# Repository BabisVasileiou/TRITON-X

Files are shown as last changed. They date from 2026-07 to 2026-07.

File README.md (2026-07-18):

<div align="center">

# 🤖 TRITON-X
### Multi-Mode Autonomous Unmanned Ground Vehicle (UGV)

**Μελέτη και Ανάπτυξη Μη Επανδρωμένου Συστήματος — Εργασία 2**
MSc Πρόγραμμα ΠΑΔΑ (PADA) · Πανεπιστήμιο Δυτικής Αττικής




[]()

*Ένα ρομποτικό όχημα εδάφους έξι λειτουργικών καταστάσεων, με τηλεχειρισμό μέσω Wi-Fi, ζωντανή μετάδοση βίντεο, αυτόνομη αποφυγή εμποδίων και χαρτογράφηση κάλυψης — βασισμένο στο μηχατρονικό μοντέλο Controller–Plant.*

[Αρχιτεκτονική](#-αρχιτεκτονική-συστήματος) ·
[Λειτουργίες](#-6-λειτουργικές-καταστάσεις-fsm) ·
[Firmware](#-λογισμικό--firmware) ·
[Τεκμηρίωση](#-τεκμηρίωση--docs) ·
[Εγκατάσταση](#-εγκατάσταση--γρήγορη-εκκίνηση)

</div>

---

## 📖 Περιγραφή Έργου

Το **TRITON-X** είναι η εξέλιξη ενός απλούστερου ρομπότ αποφυγής εμποδίων 4 αισθητήρων (Εργασία 1) σε ένα πλήρες, πολυλειτουργικό αυτόνομο όχημα εδάφους (UGV). Ο πυρήνας ελέγχου βασίζεται σε **Arduino UNO R3**, ενισχυμένος με έναν **ESP32-CAM** ως ασύρματο συνεπεξεργαστή (co-processor) για video streaming και web-based τηλεχειρισμό.

Το σύστημα ακολουθεί το **βασικό μηχατρονικό μοντέλο** (Controller–Plant–Feedback) της προδιαγραφής εργασίας: αισθητήρια (S) → μικροελεγκτής (μC) → ενεργοποιητές (A), με πλήρη ανάδραση (sensor fusion, Kalman filtering, closed-loop control).

Το ρομπότ διαθέτει **6 ανεξάρτητες λειτουργικές καταστάσεις** (Finite State Machine) — από απλό χειροκίνητο τηλεχειρισμό μέσω κινητού, μέχρι πλήρως αυτόνομη χαρτογράφηση χώρου με occupancy grid.

### Γιατί TRITON-X;

| Χαρακτηριστικό | Περιγραφή |
|---|---|
| 🎮 **Dual-mode τηλεχειρισμός** | Virtual joystick *και* έλεγχος με κλίση κινητού (gyroscope) μέσω browser |
| 📷 **Live FPV streaming** | ESP32-CAM MJPEG stream ενσωματωμένο στο web dashboard |
| 🧭 **Sensor fusion** | Kalman filtering στο υπερηχητικό, IMU 6-άξονων, 8× IR αισθητήρες, οδομετρία encoder |
| 🗺️ **Αυτόνομη χαρτογράφηση** | Boustrophedon coverage algorithm + occupancy grid 20×20, live μετάδοση στον browser |
| ⚙️ **OOP αρχιτεκτονική** | Καθαρές C++ κλάσεις (`KalmanFilter`, `Sonar`, `MotorDriver`, `OccupancyGrid`) |
| ⏱️ **Non-blocking σχεδίαση** | Αρχιτεκτονική `millis()` σε όλο το firmware — καμία μπλοκαριστική `delay()` |

---

## 🏗️ Αρχιτεκτονική Συστήματος

```
┌─────────────────────────────────────────────────────────────┐
│                      ARDUINO UNO R3                          │
│                 (Κύριος Ελεγκτής — μC)                       │
│                                                                │
│  ┌─────────── SENSORS (S) ───────────┐  ┌── ACTUATORS (A) ─┐ │
│  │ • HC-SR04 Ultrasonic (on SG90)     │  │ • L298N →        │ │
│  │ • 8× IR (4 obstacle + 4 cliff)     │  │   2× DC Motors    │ │
│  │ • MPU-6050 IMU (I2C)               │  │ • SG90 Servo      │ │
│  │ • 2× Photoelectric Encoders        │  │ • LCD 1602 (HMI)  │ │
│  │ • PCF8574T I2C Expander            │  └───────────────────┘ │
│  └─────────────────────────────────────┘                      │
│                                                                │
│         Λογική Ελέγχου: 6-mode FSM · non-blocking             │
│         millis() · Kalman Filter · OOP (C++ classes)          │
└───────────────────────────┬────────────────────────────────────┘
                             │ UART (SoftwareSerial, polling encoders)
                             │ MODE: / JOY: / GYR: / TEL: / MAP:
┌───────────────────────────┴────────────────────────────────────┐
│                    ESP32-CAM (AI-Thinker)                       │
│               (Ασύρματος Συνεπεξεργαστής)                       │
│                                                                  │
│  • Wi-Fi Access Point  ("TRITON-X")                              │
│  • HTTP Server (port 80)  — Web Dashboard                        │
│  • WebSocket Server (port 81) — Joystick / Gyro / Telemetry / Map │
│  • MJPEG Camera Stream (port 82) — OV2640                        │
└───────────────────────────┬──────────────────────────────────────┘
                             │ Wi-Fi 802.11
┌───────────────────────────┴──────────────────────────────────────┐
│                     📱 Browser (Mobile / Desktop)                  │
│  • Live FPV video feed        • Virtual joystick (touch)           │
│  • Gyroscope tilt control     • Live occupancy grid canvas         │
│  • Telemetry bar (distance, battery, state)  • Mode selector       │
└─────────────────────────────────────────────────────────────────┘
```

Πλήρες πρωτόκολλο επικοινωνίας UART μεταξύ των δύο μονάδων: [`docs/UART_PROTOCOL.txt`](docs/UART_PROTOCOL.txt)

---

## ⚡ Ισχύς — Power Architecture

Δύο **ανεξάρτητες** ρελές 5V, με κοινή γείωση, ώστε το ESP32-CAM (με τις απότομες αιχμές ρεύματος του Wi-Fi) να μην προκαλεί brown-out στο Arduino:

```
6× AA (9V) battery pack
        │
        ├──► Rocker Switch ──► L298N 12V_IN
        │                          │
        │                    Onboard 5V regulator
        │                          │
        │                          ▼
        │                  +5V_MCU rail ──► Arduino, sensors, servo
        │
        └──► DC-DC Step-Down (6.5–40V → 5V, 1.5A)
                                   │
                                   ▼
                          +5V_CAM rail ──► ESP32-CAM (exclusively)
```

> ⚠️ **Κρίσιμη σημείωση:** Η τροφοδοσία είναι πάντα **6×AA (9V)**, ποτέ Li-Po. Ο εσωτερικός ρυθμιστής του L298N **δεν επαρκεί** για τις αιχμές ρεύματος του ESP32-CAM στο Wi-Fi — απαιτείται ξεχωριστός DC-DC step-down μετατροπέας.

---

## 🎛️ 6 Λειτουργικές Καταστάσεις (FSM)

| # | Mode | Περιγραφή | Βασικά στοιχεία |
|---|---|---|---|
| 0 | **IDLE** | Κατάσταση αναμονής | Κινητήρες σταματημένοι, LCD εμφανίζει επιλογή mode |
| 1 | **MANUAL** | Τηλεχειρισμός με virtual joystick από browser | Touch UI → ESP32-CAM → UART → PWM differential drive |
| 2 | **LEVEL** | Τηλεχειρισμός με κλίση κινητού (tilt-to-drive) | DeviceOrientation API, dead-zone & smoothing filter |
| 3 | **LINE** | Ακολούθηση γραμμής | 2× IR κάτω, PD controller, ταυτόχρονη αποφυγή εμποδίων με HC-SR04 |
| 4 | **OBSTACLE** | Αυτόνομη αποφυγή εμποδίων | FSM `CRUISING → SCAN → ESCAPE → CLIFF_ESCAPE`, Kalman filter, hardware interrupts |
| 5 | **MAP** | Αυτόνομη χαρτογράφηση κάλυψης | Boustrophedon algorithm, dead-reckoning odometry, occupancy grid 20×20 |

---

## 🔧 Εξοπλισμός — Hardware

### Από Εργασία 1 (υπάρχοντα)

Arduino UNO R3 + Sensor Shield v5.0 · L298N Dual H-Bridge · 2× DC Gear Motor + caster wheel · Ακρυλικό σασί 2WD · HC-SR04 + SG90 Servo · 4× IR sensors (μπροστά) · LCD 1602 I2C

### Νέα προμήθεια για Εργασία 2

ESP32-CAM (AI-Thinker, OV2640) · DC-DC Step-Down 6.5–40V→5V 1.5A · 2× Photoelectric Encoder (18 PPR εμπειρικά) · MPU-6050 GY-521 IMU · 4× IR sensors (πίσω) · PCF8574T I2C Expander

Πλήρης χάρτης ακίδων (pin map): αντιστοιχεί στον **Πίνακα 2.4** της αναφοράς — δες το κύριο έγγραφο αναφοράς στο [`docs/`](docs/).

---

## 💻 Λογισμικό — Firmware

```
TRITON_X_UNO/              # Arduino UNO — κύριο firmware
└── TRITON_X.ino            # 6-mode FSM, OOP classes, non-blocking control loop

TRITON_X_ESP32/             # ESP32-CAM — ασύρματος συνεπεξεργαστής
└── ESP32_CAM.ino            # Wi-Fi AP, HTTP/WebSocket/MJPEG server, web dashboard
```

### Βασικές OOP κλάσεις (Arduino)

| Κλάση | Ευθύνη |
|---|---|
| `KalmanFilter` | Φιλτράρισμα θορύβου μετρήσεων HC-SR04· reset ανά γωνία σάρωσης |
| `Sonar` | Έλεγχος HC-SR04 + servo σάρωσης, non-blocking |
| `MotorDriver` | Αφαίρεση (abstraction) του L298N — differential drive, PWM |
| `OccupancyGrid` | Δομή 20×20 grid, ενημέρωση mode MAP, σειριοποίηση για μετάδοση |

### Πρωτόκολλο επικοινωνίας UART (Arduino ⇄ ESP32-CAM)

| Πρόθεμα | Κατεύθυνση | Περιεχόμενο |
|---|---|---|
| `MODE:` | ESP32 → Arduino | Αλλαγή λειτουργικής κατάστασης |
| `JOY:` | ESP32 → Arduino | Συντεταγμένες joystick (x, y) |
| `GYR:` | ESP32 → Arduino | Δεδομένα κλίσης κινητού |
| `TEL:` | Arduino → ESP32 | Τηλεμετρία (απόσταση, mode, μπαταρία) |
| `MAP:` | Arduino → ESP32 | Ενημέρωση occupancy grid κελιού |

Αναλυτικά: [`docs/UART_PROTOCOL.txt`](docs/UART_PROTOCOL.txt)

> 📌 **Γνωστός περιορισμός:** Η βιβλιοθήκη `SoftwareSerial` δεσμεύει όλα τα PCINT vectors, καθιστώντας αδύνατη τη χρήση interrupt-driven ανάγνωσης για τους encoders όταν είναι ενεργή η UART επικοινωνία με το ESP32-CAM. Οι encoders διαβάζονται επομένως με **polling**.

---

## 📚 Τεκμηρίωση — `docs/`

| Αρχείο | Περιεχόμενο |
|---|---|
| [`README_FIRST.txt`](docs/README_FIRST.txt) | Οδηγός εκκίνησης — τι να διαβάσεις πρώτο |
| [`UART_PROTOCOL.txt`](docs/UART_PROTOCOL.txt) | Πλήρης προδιαγραφή πρωτοκόλλου επικοινωνίας Arduino ⇄ ESP32-CAM |
| [`VALIDATION_REPORT.txt`](docs/VALIDATION_REPORT.txt) | Αποτελέσματα δοκιμών ανά λειτουργική κατάσταση |
| [`CHANGELOG.txt`](docs/CHANGELOG.txt) | Ιστορικό εκδόσεων firmware |
| [`SHA256_MANIFEST.txt`](docs/SHA256_MANIFEST.txt) | Checksums αρχείων για επαλήθευση ακεραιότητας |

---

## 🚀 Εγκατάσταση & Γρήγορη Εκκίνηση

### Προαπαιτούμενα

- [Arduino IDE](https://www.arduino.cc/en/software) 2.x
- Board package: **ESP32 by Espressif Systems** (Boards Manager)
- Βιβλιοθήκες: `Servo`, `Wire`, `LiquidCrystal_I2C`, `SoftwareSerial`, `WebSocketsServer` (Links2004), `ArduinoJson`, `esp32-camera`

### Βήματα

1. **Clone το repository**
   ```bash
   git clone https://github.com/BabisVasileiou/TRITON-X.git
   cd TRITON-X
   ```

2. **Arduino UNO** — άνοιξε `TRITON_X_UNO/TRITON_X.ino`, επίλεξε board *Arduino Uno*, upload.

3. **ESP32-CAM** — άνοιξε `TRITON_X_ESP32/ESP32_CAM.ino`, board *AI Thinker ESP32-CAM*.
   ⚠️ Χρειάζεται εξωτερικό USB-TTL adapter (GPIO0 → GND κατά το flashing). Μετά το upload, αφαίρεσε τη γέφυρα και κάνε reset.

4. **Σύνδεση** — ενεργοποίησε το ρομπότ, σύνδεσε το κινητό στο Wi-Fi **`TRITON-X`**, άνοιξε browser στο `http://192.168.4.1`, επίλεξε mode.

---

## 👤 Συγγραφέας

**Βασιλείου Χαράλαμπος**
MSc DRONES — Πανεπιστήμιο Δυτικής Αττικής
Μάθημα: Μελέτη και Ανάπτυξη Μη Επανδρωμένου Συστήματος

## 📜 Άδεια Χρήσης

Το firmware διανέμεται υπό την άδεια [MIT](LICENSE).

---

<div align="center">

*Αναπτύχθηκε ως τμήμα του μαθήματος "Μελέτη και Ανάπτυξη Μη Επανδρωμένου Συστήματος" — ΠΑΔΑ, 2026*

</div>

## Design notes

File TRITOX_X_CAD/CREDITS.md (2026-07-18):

# Αναφορά Πηγών Τρισδιάστατων Μοντέλων (CAD Attribution)

Το assembly του TRITON-X ενσωματώνει έτοιμα 3D μοντέλα εξαρτημάτων (Arduino, αισθητήρες, driver, κλπ.) τα οποία **δεν σχεδιάστηκαν από τον συγγραφέα** αλλά ελήφθησαν από δημόσιες βιβλιοθήκες CAD. Σύμφωνα με ακαδημαϊκή δεοντολογία και τους όρους χρήσης των περισσότερων πλατφορμών (GrabCAD, Thingiverse κ.ά.), κάθε τέτοιο μοντέλο αναφέρεται ρητά παρακάτω, με τον αρχικό δημιουργό και την πηγή.

> Τα μοντέλα αυτά χρησιμοποιούνται **αποκλειστικά για ακαδημαϊκή/εκπαιδευτική οπτικοποίηση** της διάταξης εντός του assembly `triton_x_assembly.SLDASM`, και δεν αποτελούν πρωτότυπη εργασία του συγγραφέα. Η γεωμετρία του σασί, των στηριγμάτων αισθητήρων (mounts) και κάθε custom εξαρτήματος σχεδιάστηκε από τον συγγραφέα και εξαιρείται από τον παρακάτω πίνακα.

## Πίνακας Πηγών

| # | Εξάρτημα (στο assembly) | Δημιουργός / Publisher | Πηγή (link) | Άδεια χρήσης |
|---|---|---|---|---|
| 1 | Σασί + κινητήρες + τροχοί (chassis+motors+wheels) | Mukarram Ibrahim | [grabcad.com/library/smart-car-kit-mechanical-design-for-educational-robotics-platform-1](https://grabcad.com/library/smart-car-kit-mechanical-design-for-educational-robotics-platform-1) | GrabCAD Open Engineering |
| 2 | Arduino UNO R3 | Andrew Whitham | [grabcad.com/library/arduino-uno-r3-1](https://grabcad.com/library/arduino-uno-r3-1) | GrabCAD Open Engineering |
| 3 | Arduino Sensor Shield v5.0 | Tijani JOUINI | [grabcad.com/library/sensor-shield-v5-0-1](https://grabcad.com/library/sensor-shield-v5-0-1) | GrabCAD Open Engineering |
| 4 | ESP32-CAM | Dũng Phan | [grabcad.com/library/esp32-cam-wifi-bluetooth-1](https://grabcad.com/library/esp32-cam-wifi-bluetooth-1) | GrabCAD Open Engineering |
| 5 | PCF8574 I2C Expander | roberto valeri | [grabcad.com/library/pcf8574-multiplexer-1](https://grabcad.com/library/pcf8574-multiplexer-1) | GrabCAD Open Engineering |
| 6 | L298N Motor Driver | NITHISH CADEX | [grabcad.com/library/motor-driver-l298n-2](https://grabcad.com/library/motor-driver-l298n-2) | GrabCAD Open Engineering |
| 7 | Photoelectric Encoder | Gauthier Heiss | [grabcad.com/library/feetech-speed-sensor-ft-en-001-1](https://grabcad.com/library/feetech-speed-sensor-ft-en-001-1) | GrabCAD Open Engineering |
| 8 | HC-SR04 Ultrasonic | Henrique Fernandes | [grabcad.com/library/sensor-ultrassonico-hc-sr04-1](https://grabcad.com/library/sensor-ultrassonico-hc-sr04-1) | GrabCAD Open Engineering |
| 9 | SG90 Micro Servo | Matheus Frasson | [grabcad.com/library/sg90-micro-servo-9g-tower-pro-1](https://grabcad.com/library/sg90-micro-servo-9g-tower-pro-1) | GrabCAD Open Engineering |
| 10 | IR Sensor (Obstacle) | MRMS - WORKSHOP | [grabcad.com/library/ir-sensor-7](https://grabcad.com/library/ir-sensor-7) | GrabCAD Open Engineering |
| 11 | IR Sensor (Cliff, HW-201) | Gaborcz | [grabcad.com/library/hw-201-2](https://grabcad.com/library/hw-201-2) | GrabCAD Open Engineering |
| 12 | MPU-6050 Accelerometer/Gyro Module | Nelson Stoldt | [grabcad.com/library/mpu6050-accelerometer-module-1](https://grabcad.com/library/mpu6050-accelerometer-module-1) | GrabCAD Open Engineering |
| 13 | LCD 1602 I2C (16x2 Character Display) | Anders Lohmann | [grabcad.com/library/16x2-character-lcd-display-1](https://grabcad.com/library/16x2-character-lcd-display-1) | GrabCAD Open Engineering |
| 14 | Battery Holder (6× AA) | Hallo | [grabcad.com/library/battery-holder-5xaa-1](https://grabcad.com/library/battery-holder-5xaa-1) | GrabCAD Open Engineering |
| 15 | Rocker Switch (KCD1, 2-Pin) | PENNEL Patrice | [grabcad.com/library/kcd1-on-off-rocker-switch-2-pins-1](https://grabcad.com/library/kcd1-on-off-rocker-switch-2-pins-1) | GrabCAD Open Engineering |
| 16 | DC-DC Step-Down Converter | MainDesign | [grabcad.com/library/usb-dc-dc-step-down-1](https://grabcad.com/library/usb-dc-dc-step-down-1) | GrabCAD Open Engineering |

> ⚠️ **Σημείωση για τη στήλη "Άδεια χρήσης":** Όλα τα παραπάνω μοντέλα προέρχονται από το GrabCAD, όπου η προεπιλεγμένη άδεια δημοσίευσης είναι η **"GrabCAD Open Engineering"**, η οποία επιτρέπει ελεύθερη χρήση/τροποποίηση με υποχρεωτική αναφορά του δημιουργού. Πριν την τελική παράδοση, **επιβεβαίωσε ξεχωριστά σε κάθε σελίδα του GrabCAD** ότι δεν αναγράφεται διαφορετική/αυστηρότερη άδεια (σπάνιο αλλά πιθανό), ειδικά για τα part #1 (πλήρες σασί kit) και #16 (DC-DC converter), όπου μερικοί δημιουργοί περιορίζουν σε "Non-Commercial only".

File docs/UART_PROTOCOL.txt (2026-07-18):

================================================================
TRITON-X COMMUNICATION PROTOCOL  --  v4.0 Final
Newline-delimited ASCII lines. UART 9600 8N1 (ESP32 <-> UNO).
WebSocket text frames (Browser <-> ESP32, port 81).
================================================================

1. ESP32 -> ARDUINO UNO
----------------------------------------------------------------
  HB                    Link heartbeat, sent every 250 ms. The
                        UNO stops any running mode if no HB is
                        received for 1500 ms.
  MODE:MANUAL           Select a mode. Selection always performs
  MODE:LEVEL            a full safe transition (motors stop, all
  MODE:LINE             FSMs reset, servo centered) and then
  MODE:OBSTACLE         waits for START.
  MODE:MAPPING          Selecting MAPPING also zeros pose,
                        encoders and the ESP32 grid.
  CMD:START             Arm and run the selected mode.
  CMD:STOP              Immediate stop; mode stays selected.
  CMD:CLEAR_LOCK        Request release of a latched CLIFF LOCK.
                        Granted only on confirmed safe floor.
  CMD:RESET_MAP         Stop, zero pose/encoders and clear map.
  JOY:x,y               MANUAL command, x/y in -100..+100.
                        Sent every 100 ms, including neutral
                        JOY:0,0 (watchdog keep-alive).
  TLT:forward,turn      LEVEL command, values in -100..+100.

2. ARDUINO UNO -> ESP32
----------------------------------------------------------------
  MODE:<name>           Confirms the completed mode transition.

  EVENT:<text>          Asynchronous events, e.g. STARTED,
                        STOPPED, CLIFF_DETECTED, CLIFF_LOCKED,
                        CLIFF_CLEARED, SAFETY_LOCK_CLEARED,
                        CLEAR_LOCK_REJECTED, MAP_RESET,
                        MANUAL_COMMAND_TIMEOUT,
                        LEVEL_COMMAND_TIMEOUT,
                        LINE_OBSTACLE_STOP, OBSTACLE_FRONT,
                        BROWSER_LINK_LOST, PCF_FAULT_STOP,
                        START_REJECTED_NO_MODE,
                        START_REJECTED_LOCKED,
                        START_REJECTED_PCF, START_REJECTED_MPU.

  SYS:<10 fields>       Periodic system telemetry (250 ms; 500 ms
                        in MAPPING). Comma-separated:
                        mode, running(0/1), safety, modeState,
                        cliffBits(hex), obstacleBits(hex),
                        pcfHealthy(0/1), mpuHealthy(0/1),
                        sonarCm(0.1), headingDeg(0.1).
                        Bit order (bit0..bit3) for both the
                        cliff and the obstacle byte:
                        FrontLeft=bit0, FrontRight=bit1,
                        RearLeft=bit2, RearRight=bit3.

  POSE:<9 fields>       MAPPING pose telemetry every 250 ms:
                        x, y, headingDeg, sonarCm, state,
                        encLeft, encRight, travelCm, elapsedSec.

  RAY:<5 fields>        One world-referenced sonar ray:
                        originX, originY, bearingDeg,
                        distanceCm, hit(0/1).

3. BROWSER <-> ESP32 (WebSocket, port 81)
----------------------------------------------------------------
  Browser -> ESP32:
    CTRL:HB             Controller heartbeat. Loss for 4000 ms
                        forces STOP and disables the camera.
    CAM:ON / CAM:OFF    Enable / disable the MJPEG stream.
    CMD:RESET_MAP       Clears ESP32 grid, forwards to the UNO.
    MODE:<name>, CMD:START, CMD:STOP, CMD:CLEAR_LOCK,
    JOY:x,y, TLT:f,t    Forwarded to the UNO unchanged.

  ESP32 -> Browser:
    CTRL:ACTIVE         This client is the single controller.
    CTRL:BUSY           Another controller is already active.
    CAM:ON/OFF/ERROR    Camera state notification.
    TEL:{json}          Consolidated telemetry every 500 ms:
                        uno, mode, running, safety, cliff,
                        obstacle, pcf, mpu, sonar, heading,
                        x, y, state, encL, encR, travel,
                        elapsed, event, cameraReady, cameraOn.
    MAP:<900 chars>     Occupancy grid, row-major 30x30, one
                        character per cell:
                        0 unknown, 1 free, 2 occupied,
                        3 robot path. Broadcast every 1000 ms
                        while MAPPING is selected.
    EVENT:<text>        Forwarded UNO events.

4. SAFETY CHAIN SUMMARY
----------------------------------------------------------------
  Browser heartbeat lost (4 s)  -> ESP32 sends CMD:STOP.
  Browser disconnects           -> ESP32 sends CMD:STOP.
  UNO heartbeat lost (1.5 s)    -> UNO stops the running mode.
  JOY/TLT command lost (0.5 s)  -> MANUAL/LEVEL watchdog stop
                                   and neutral re-arm.
  Cliff detected                -> global recovery FSM, possible
                                   latched CLIFF LOCK.
================================================================

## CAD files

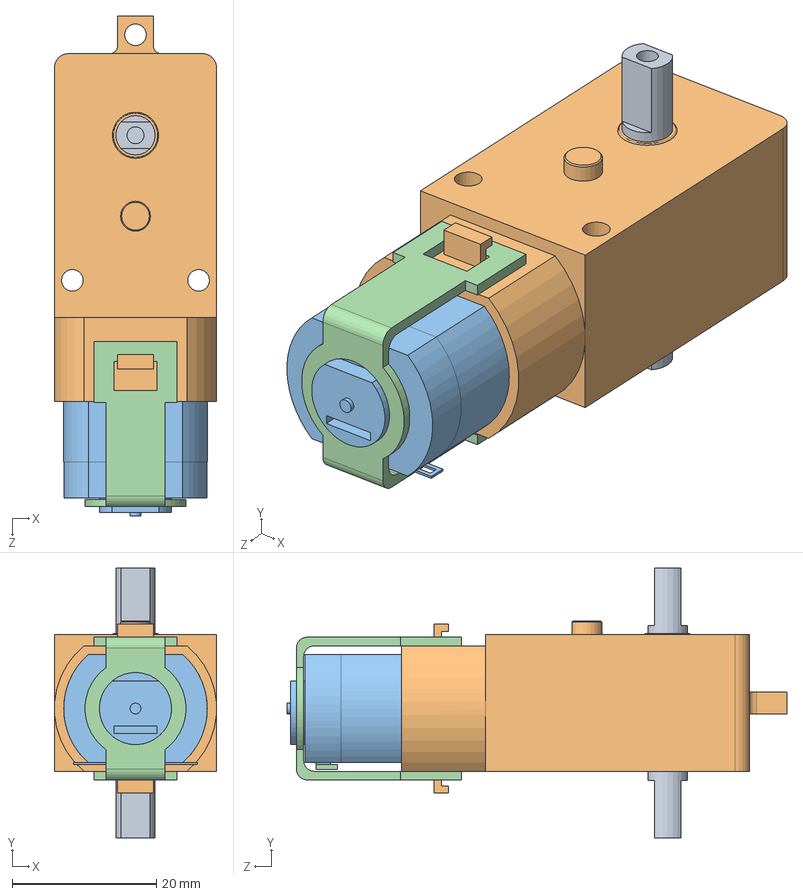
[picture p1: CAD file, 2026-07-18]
TRITOX_X_CAD/DC Motor.SLDASM
22.5 x 37.4 x 69.3 mm
Motor Shaft
Motor Casing
Driving Motor
Fasteners

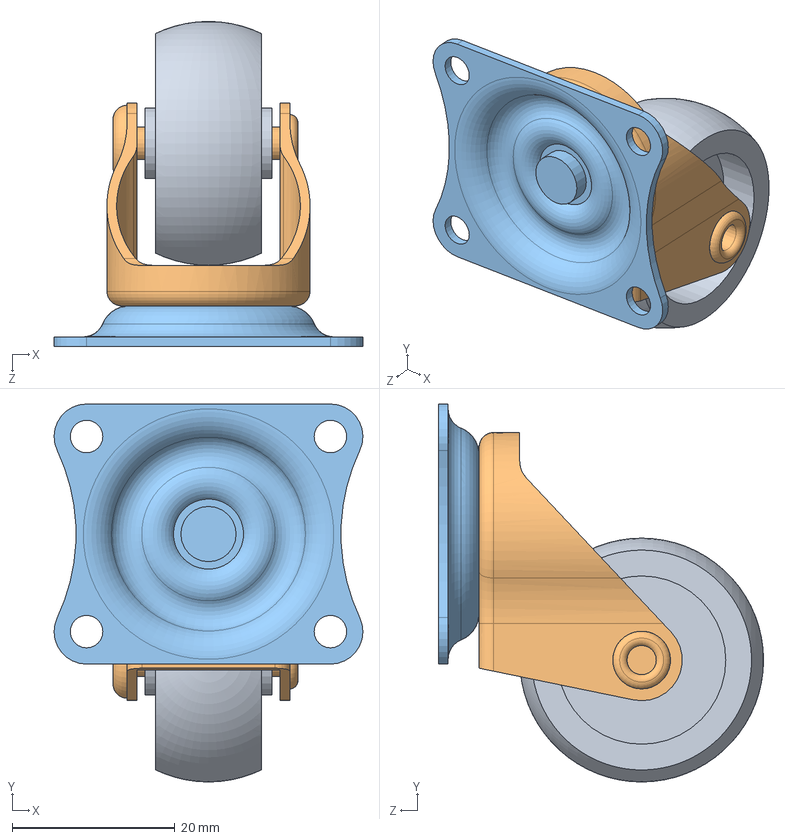
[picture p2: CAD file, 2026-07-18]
TRITOX_X_CAD/40mm rear wheel assy.SLDASM
38.0 x 46.5 x 40.0 mm
Caster_40mm_Wheel_30mm_01
Caster_40mm_Wheel_support_01
Caster_40mm_Swivel_plate_01

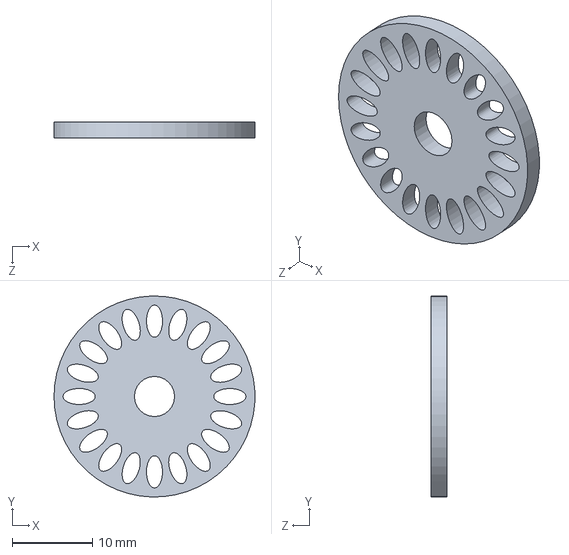
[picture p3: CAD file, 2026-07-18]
TRITOX_X_CAD/disk.SLDPRT
25.0 x 25.0 x 2.00 mm

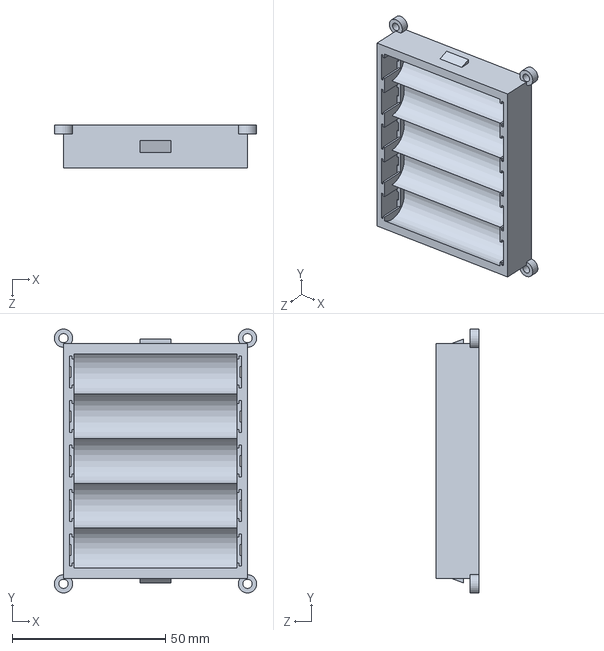
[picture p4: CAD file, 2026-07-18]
TRITOX_X_CAD/Battery holder 5xAA.step.SLDPRT
66.0 x 86.0 x 14.0 mm

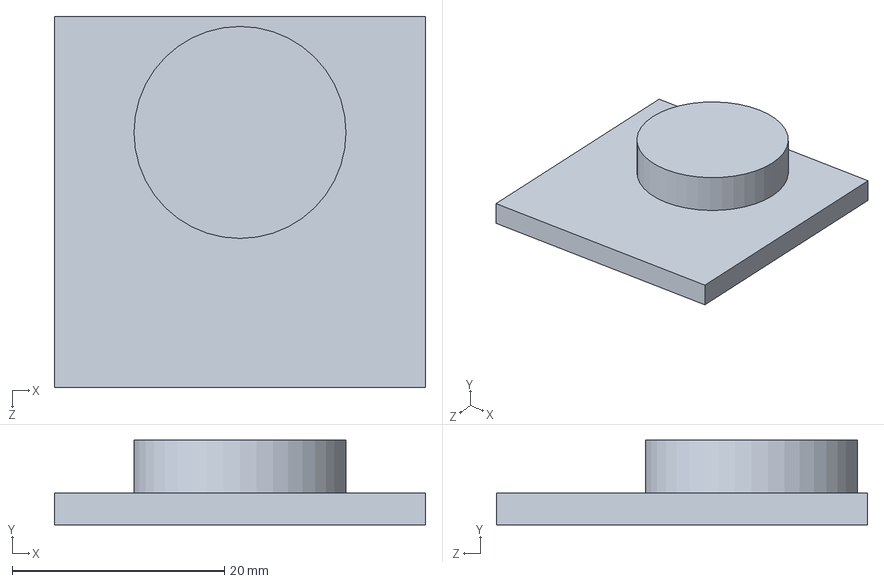
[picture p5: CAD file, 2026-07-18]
TRITOX_X_CAD/bash.SLDPRT
35.0 x 8.00 x 35.0 mm

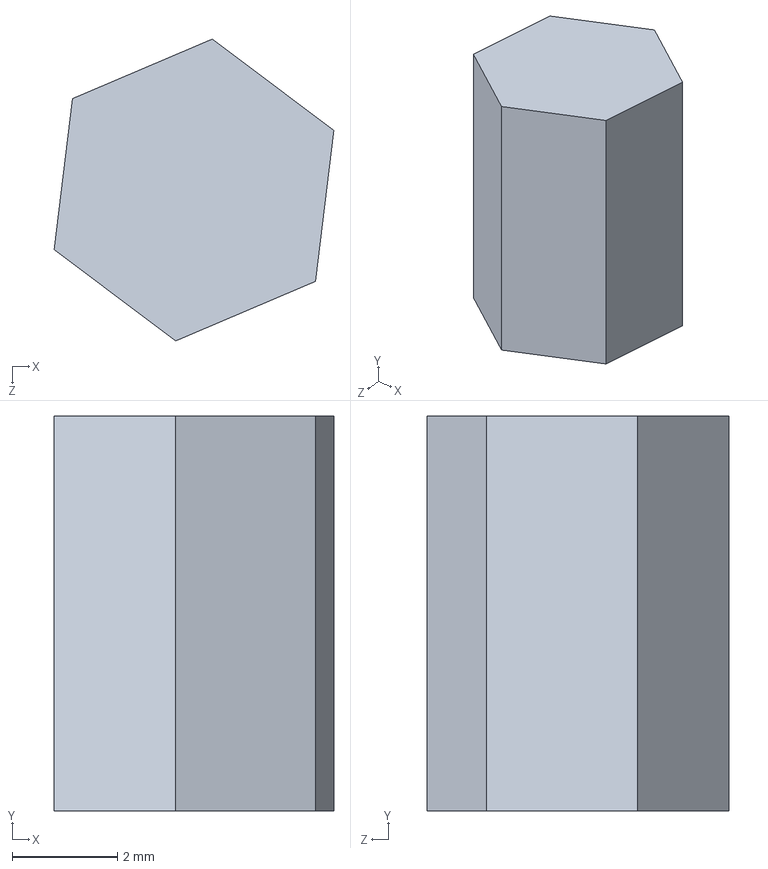
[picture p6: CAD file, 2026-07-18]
TRITOX_X_CAD/20.SLDPRT
5.31 x 7.50 x 5.73 mm

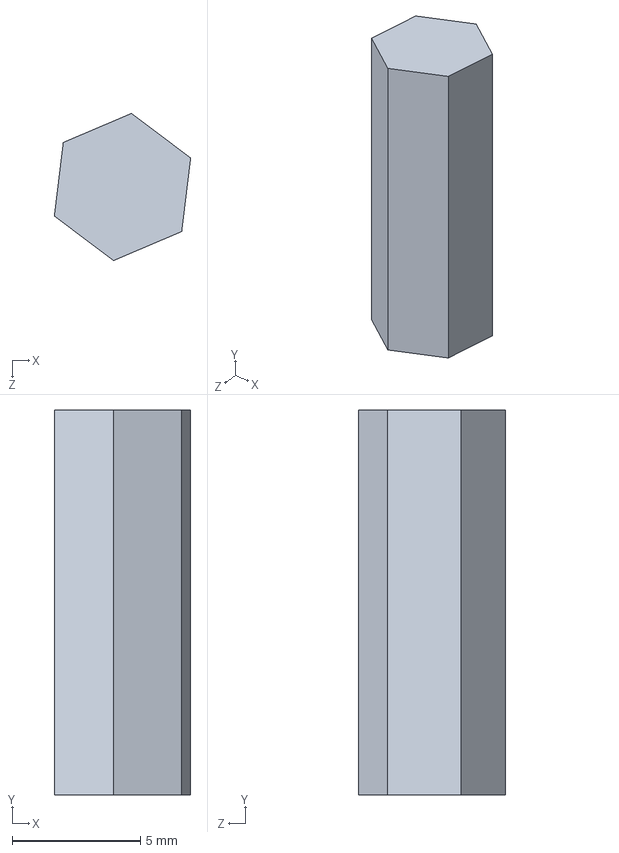
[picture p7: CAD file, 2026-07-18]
TRITOX_X_CAD/15.SLDPRT
5.31 x 15.0 x 5.73 mm

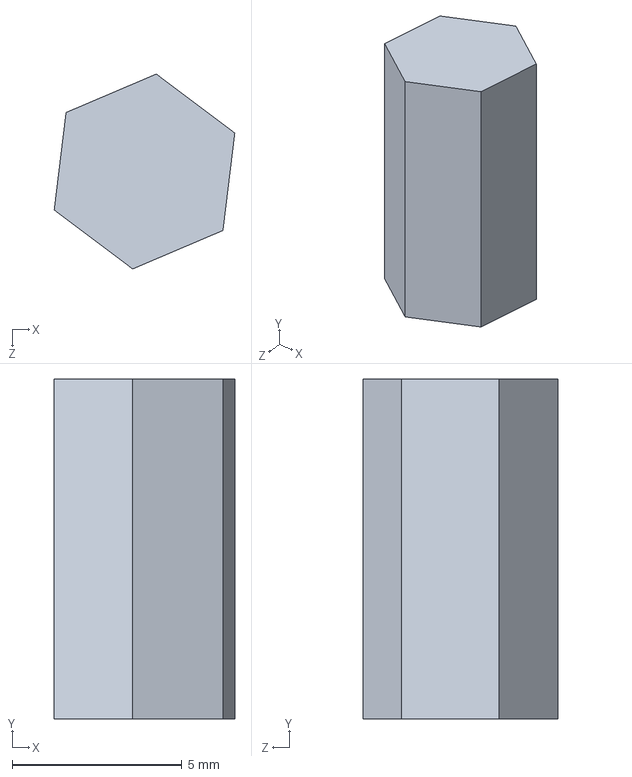
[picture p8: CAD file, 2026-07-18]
TRITOX_X_CAD/10.SLDPRT
5.31 x 10.0 x 5.73 mm

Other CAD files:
TRITOX_X_CAD/Driving Motor.sldprt
TRITOX_X_CAD/Caster_40mm_Wheel_30mm_01.sldprt
TRITOX_X_CAD/Caster_40mm_Wheel_support_01.sldprt
TRITOX_X_CAD/Caster_40mm_Swivel_plate_01.sldprt
TRITOX_X_CAD/Battery holder 5xAA.step

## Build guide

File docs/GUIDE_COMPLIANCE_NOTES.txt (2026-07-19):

TRITON-X CODE-GUIDE COMPLIANCE UPDATE
=====================================

The executable algorithms, constants, pin assignments, state transitions,
commands and simulation behaviour have not been changed.

Changes applied:
- Standard program headers with Purpose, Hardware, Software and Reference.
- Standard function headers with Purpose, Arguments, Results, Hardware,
  Software and Reference.
- Missing class documentation added where required.
- Source and comment lines limited to 80 ASCII characters.
- Non-ASCII dash characters replaced with ASCII hyphens.
- Long expressions were wrapped without changing their values or logic.

Prepared for C. Vasileiou, July 2026.

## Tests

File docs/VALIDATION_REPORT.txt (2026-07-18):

================================================================
TRITON-X VALIDATION REPORT  --  v4.0 Final
C. Vasileiou, MSc PADA, July 2026
================================================================

1. STATIC CODE CHECKS (PASSED)
----------------------------------------------------------------
  [x] All source lines are at most 80 characters.
  [x] All comments are English ASCII; no non-ASCII bytes exist
      in any source file.
  [x] No String objects on the Arduino UNO (fixed C buffers and
      flash-resident strings only; no heap fragmentation).
  [x] No SoftwareSerial anywhere; UNO-side UART is the Timer2
      implementation in TimerUart.h, preserving the D10/D12
      encoder pin-change interrupt.
  [x] No dynamic allocation on the UNO; all state is static.
  [x] Every function and file carries the standard header block
      (Purpose / Arguments / Results / Hardware / Software /
      Reference).
  [x] Cross-checked protocol field counts: SYS 10 fields,
      POSE 9 fields, RAY 5 fields match the ESP32 parsers.
  [x] UART pin cross-check: UNO D4 RX <- ESP32 GPIO13 TX and
      UNO D13 TX -> ESP32 GPIO14 RX match both Configuration.h
      files and the TimerUart register-level pin access
      (PD4 read, PB5 write).
  [x] Dashboard JavaScript syntax verified before gzip
      compression; compressed payload about 7.6 KB.

2. COMPILATION (PASSED ON TARGET TOOLCHAINS)
----------------------------------------------------------------
  [x] TRITON_X_UNO compiles for Arduino UNO:
      Flash 25,650 bytes (79%), SRAM 767 bytes (37%),
      free SRAM 1,281 bytes.
  [x] TRITON_X_ESP32 compiles for AI Thinker ESP32-CAM:
      Flash 1,139,368 bytes (36%), RAM 62,516 bytes (19%),
      free RAM 265,164 bytes.

3. HARDWARE VALIDATION (PASSED ON THE PHYSICAL ROBOT)
----------------------------------------------------------------
  [x] MANUAL: joystick drive, neutral arming, continuous
      JOY keep-alive (100 ms), 500 ms watchdog stop.
  [x] LEVEL: phone tilt drive, neutral calibration, dead zone,
      500 ms watchdog stop.
  [x] LINE: PD following (Kp=1.5, Kd=0.3, PWM 110), crossing
      handling, 15 cm sonar terminal stop.
  [x] OBSTACLE: Guardian FSM cruise/scan/decide, Kalman-filtered
      sonar, rear-aware reverse, dead-end recovery, anti-loop
      U-turn after three consecutive turns.
  [x] MAPPING: heading-held cruise, periodic room survey,
      encoder+gyro dead reckoning, live 30x30 occupancy grid,
      automatic pose/map reset on mode reselection.
  [x] Global cliff safety across MANUAL, LEVEL, OBSTACLE and
      MAPPING, including direction-aware escape, latched
      CLIFF LOCK and guarded CLEAR SAFETY LOCK.
  [x] Camera MJPEG stream (QVGA, about 10 fps) standalone and
      concurrently with the dashboard and with MAPPING.
  [x] Wi-Fi AP stability with modem sleep disabled
      (WiFi.setSleep(false)).
  [x] Browser-disconnect STOP and browser-heartbeat-loss STOP.
  [x] UNO-offline detection on the dashboard.

4. DOCUMENTED DESIGN CHARACTERISTICS (NOT DEFECTS)
----------------------------------------------------------------
  - MAPPING is dead-reckoning occupancy mapping, not SLAM;
    gradual drift is expected and stated as future work (LIDAR).
  - The two-sensor LINE layout cannot distinguish centered
    travel from a lost line; sensors sit outside the tape.
  - The obstacle Kalman estimate re-initializes at mode entry
    and converges within the first few sonar samples.
  - The occupancy grid resides on the ESP32 (900 cells) to
    preserve the 2 KB UNO SRAM.
================================================================

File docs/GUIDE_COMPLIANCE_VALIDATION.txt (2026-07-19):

TRITON-X GUIDE COMPLIANCE VALIDATION
====================================

Package: 01_GITHUB_TRITON_X_GUIDE_COMPLIANT

PASS - All C/C++ source and comment lines are at most 80 characters.
PASS - All C/C++ source and comments use ASCII characters.
PASS - Program headers contain Purpose, Hardware, Software and Reference.
PASS - C/C++ functions use standardized documentation headers.
PASS - Naming and indentation conventions were retained.
- Executable C/C++ token stream is identical to the original RC5
  package after comments and whitespace are removed.
- Existing RC5 static validation results remain applicable because
  no executable source token was changed.

Prepared for C. Vasileiou, July 2026.

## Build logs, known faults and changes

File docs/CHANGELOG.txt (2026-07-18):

================================================================
TRITON-X CHANGELOG  --  Integrated firmware line
================================================================

v4.0 Final (July 2026)
----------------------------------------------------------------
  - Release freeze of the hardware-validated RC5 code base.
  - Version identifiers unified to "v4.0 Final" in every file.
  - Companion documentation rewritten as a single consistent
    set (README, protocol, validation report, changelog,
    SHA-256 manifest); historical RC notes removed.
  - No functional code changes relative to RC5.

v4.0-rc5
----------------------------------------------------------------
  - MANUAL fix: the dashboard sends JOY commands every 100 ms,
    including neutral JOY:0,0, so the 500 ms UNO watchdog no
    longer trips while the joystick rests at center.

v4.0-rc4
----------------------------------------------------------------
  - Camera subsystem: initialize once at boot; CAMERA ON only
    enables the prepared stream (cannot block WebSocket
    heartbeats). Dedicated MJPEG server on port 82.
  - Wi-Fi stability: modem sleep disabled, TX power fixed,
    single-client AP.

v4.0-rc3
----------------------------------------------------------------
  - Dashboard stored as a gzip-compressed PROGMEM byte array
    (about 7.6 KB); faster load and lower RAM usage.
  - Faster UI feedback paths.

v4.0-rc2
----------------------------------------------------------------
  - WebSockets library compatibility fix (broadcastTXT requires
    a named String lvalue).
  - Compile fixes for the ESP32 Arduino core.

v4.0-rc1
----------------------------------------------------------------
  - First unification of the five validated standalone modes
    (MANUAL v1.2, LEVEL v1.2, LINE v1.0, OBSTACLE standalone,
    MAPPING v1.4) under one Arduino UNO firmware with a global
    cliff safety supervisor, ModeManager, shared hardware layer
    and the Timer2 UART.

Pre-integration standalone lineage
----------------------------------------------------------------
  - MAPPING v1.4: encoder+gyro dead reckoning, UART2 at 9600,
    heading-hold cruise, room survey scans.
  - MANUAL/LEVEL v1.2: neutral re-arming, command watchdogs,
    validated cliff recovery timings (90 PWM cliff turn).
  - LINE v1.0: two-sensor PD follower, sonar terminal stop.
  - OBSTACLE standalone: Guardian FSM with Kalman sonar filter.
================================================================

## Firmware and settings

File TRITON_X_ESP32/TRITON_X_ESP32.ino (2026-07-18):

/********** TRITON-X integrated gateway (ESP32-CAM)
 * Purpose
 *   Hosts the unified browser control station, bridges five-mode
 *   commands to the Arduino UNO, builds the occupancy map and serves an
 *   optional QVGA MJPEG camera stream.
 * Hardware
 *   AI-Thinker ESP32-CAM with OV2640. UART2 GPIO13 TX -> Arduino D4 RX;
 *   GPIO14 RX <- level-shifted Arduino D13 TX. microSD is not used.
 * Software
 *   Wi-Fi AP; HTTP 80; WebSocket 81; MJPEG 82; 9600 baud UART2.
 * Safety
 *   One active browser controller is permitted. Its disconnection sends
 *   STOP immediately. Camera control is independent of drive mode.
 * Limitations
 *   QVGA is selected to preserve Wi-Fi and mapping responsiveness.
 * Reference
 *   v4.0 Final, C. Vasileiou, MSc PADA, July 2026.
 **********/

#include <Arduino.h>
#include <WiFi.h>
#include <WebServer.h>
#include <WebSocketsServer.h>
#include <math.h>
#include <stdlib.h>
#include <string.h>

#include "Configuration.h"
#include "MappingGrid.h"
#include "CameraServer.h"
#include "dashboard.h"
#include "RobotProtocol.h"

/******** function handleRoot
 * Purpose
 *   Serves the unified dashboard from program flash.
 * Arguments
 *   None.
 * Results
 *   Updates state and/or hardware and returns no value.
 * Hardware
 *   Uses ESP32-CAM communication or camera resources as required.
 * Software
 *   Uses bounded state and the ESP32 framework communication APIs.
 * Reference
 *   v4.0 Final, C. Vasileiou, July 2026.
 **********/
void handleRoot(void) {
  httpServer.sendHeader("Content-Encoding", "gzip");
  httpServer.sendHeader("Cache-Control", "no-store");
  httpServer.send_P(
    200,
    "text/html; charset=utf-8",
    (PGM_P)DASHBOARD_GZIP,
    DASHBOARD_GZIP_SIZE
  );
}

/******** function setup
 * Purpose
 *   Initializes the controller, peripherals and communication services.
 * Arguments
 *   None.
 * Results
 *   Updates state and/or hardware and returns no value.
 * Hardware
 *   Uses ESP32-CAM communication or camera resources as required.
 * Software
 *   Uses bounded state and the ESP32 framework communication APIs.
 * Reference
 *   v4.0 Final, C. Vasileiou, July 2026.
 **********/
void setup(void) {
  Serial.begin(115200);
  robotSerial.begin(
    ROBOT_BAUD,
    SERIAL_8N1,
    ROBOT_RX_PIN,
    ROBOT_TX_PIN
  );

  clearMap();
  WiFi.mode(WIFI_AP);
  WiFi.setSleep(false);
  WiFi.setTxPower(WIFI_POWER_19_5dBm);
  WiFi.softAP(
    AP_SSID,
    AP_PASSWORD,
    AP_CHANNEL,
    false,
    AP_MAX_CLIENTS
  );

  httpServer.on("/", HTTP_GET, handleRoot);
  httpServer.on("/favicon.ico", HTTP_GET, []() {
    httpServer.send(204, "text/plain", "");
  });
  httpServer.onNotFound([]() {
    httpServer.send(404, "text/plain", "Not found");
  });
  httpServer.begin();

  webSocket.begin();
  webSocket.onEvent(onWebSocketEvent);

  /*
   * Initialize the camera once during startup. CAMERA ON only enables
   * the already prepared stream and therefore cannot block WebSocket
   * heartbeat processing.
   */
  cameraReady = initializeCamera();
  if (cameraReady) {
    cameraReady = startCameraServer();
  }
  cameraAvailable = cameraReady;
  cameraEnabled = false;

  Serial.print(F("Camera: "));
  if (cameraReady) {
    Serial.println(F("READY"));
  } else {
    Serial.print(F("ERROR 0x"));
    Serial.println((uint32_t)cameraLastError, HEX);
  }

  sendStop();
}

/******** function loop
 * Purpose
 *   Runs the non-blocking supervisor and selected mode continuously.
 * Arguments
 *   None.
 * Results
 *   Updates state and/or hardware and returns no value.
 * Hardware
 *   Uses ESP32-CAM communication or camera resources as required.
 * Software
 *   Uses bounded state and the ESP32 framework communication APIs.
 * Reference
 *   v4.0 Final, C. Vasileiou, July 2026.
 **********/
void loop(void) {
  serviceProtocol();
}

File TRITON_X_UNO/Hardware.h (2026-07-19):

/********** TRITON-X common hardware layer
 * Purpose
 *   Provides one shared implementation for motors, sonar, I2C inputs,
 *   MPU-6050 heading, wheel encoders, LCD and sensor filtering.
 * Hardware
 *   The exact pin allocation is defined in Configuration.h.
 * Software
 *   Non-blocking sensor filtering is combined with 10 ms odometry.
 * Safety
 *   PCF8574 communication failure is latched and prevents operation.
 * Reference
 *   v4.0-rc5, derived from validated standalone tests and MAPPING v1.4,
 *   C. Vasileiou, July 2026.
 **********/

#ifndef TRITON_X_HARDWARE_H
#define TRITON_X_HARDWARE_H

#include <Arduino.h>
#include <Wire.h>
#include <Servo.h>
#include <LiquidCrystal_I2C.h>
#include <math.h>

volatile long encoderLeftTicks = 0;
volatile long encoderRightTicks = 0;
volatile int8_t leftMotorDirection = 0;
volatile int8_t rightMotorDirection = 0;
volatile uint8_t previousPortB = 0;
volatile bool frontCliffInterruptFlag = false;

/******** function ISR
 * Purpose
 *   Services the time-critical interrupt associated with this module.
 * Arguments
 *   PCINT0_vect Value supplied to the isr operation.
 * Results
 *   Updates state and/or hardware and returns no value.
 * Hardware
 *   Uses the shared Arduino UNO hardware layer as required.
 * Software
 *   Uses fixed state and bounded operations; no dynamic allocation.
 * Reference
 *   v4.0-rc5, C. Vasileiou, July 2026.
 **********/
ISR(PCINT0_vect) {
  uint8_t currentPortB = PINB;
  bool leftNow = (currentPortB & _BV(PB2)) != 0;
  bool leftBefore = (previousPortB & _BV(PB2)) != 0;
  bool rightNow = (currentPortB & _BV(PB4)) != 0;
  bool rightBefore = (previousPortB & _BV(PB4)) != 0;

  if (leftNow && !leftBefore && leftMotorDirection != 0) {
    encoderLeftTicks += leftMotorDirection;
  }
  if (rightNow && !rightBefore && rightMotorDirection != 0) {
    encoderRightTicks += rightMotorDirection;
  }
  previousPortB = currentPortB;
}

/******** function wrapAngle180
 * Purpose
 *   Normalizes an angle to the interval -180 to +180 degrees.
 * Arguments
 *   angle Servo or geometric angle in degrees.
 * Results
 *   Returns the calculated value as a floating-point number.
 * Hardware
 *   Uses the shared Arduino UNO hardware layer as required.
 * Software
 *   Uses fixed state and bounded operations; no dynamic allocation.
 * Reference
 *   v4.0-rc5, C. Vasileiou, July 2026.
 **********/
float wrapAngle180(float angle) {
  while (angle > 180.0f) {
    angle -= 360.0f;
  }
  while (angle <= -180.0f) {
    angle += 360.0f;
  }
  return angle;
}

/******** function angleDifference
 * Purpose
 *   Calculates the signed shortest angular error.
 * Arguments
 *   target Target angle in degrees.
 *   current Current angle in degrees.
 * Results
 *   Returns the calculated value as a floating-point number.
 * Hardware
 *   Uses the shared Arduino UNO hardware layer as required.
 * Software
 *   Uses fixed state and bounded operations; no dynamic allocation.
 * Reference
 *   v4.0-rc5, C. Vasileiou, July 2026.
 **********/
float angleDifference(float target, float current) {
  return wrapAngle180(target - current);
}

/******** function distanceBetween
 * Purpose
 *   Calculates planar distance between two positions.
 * Arguments
 *   x1 First X coordinate in centimetres.
 *   y1 First Y coordinate in centimetres.
 *   x2 Second X coordinate in centimetres.
 *   y2 Second Y coordinate in centimetres.
 * Results
 *   Returns the calculated value as a floating-point number.
 * Hardware
 *   Uses the shared Arduino UNO hardware layer as required.
 * Software
 *   Uses fixed state and bounded operations; no dynamic allocation.
 * Reference
 *   v4.0-rc5, C. Vasileiou, July 2026.
 **********/
float distanceBetween(float x1, float y1, float x2, float y2) {
  float dx = x2 - x1;
  float dy = y2 - y1;
  return sqrt(dx * dx + dy * dy);
}
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

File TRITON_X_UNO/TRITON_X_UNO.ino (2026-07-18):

/********** TRITON-X integrated five-mode controller (Arduino UNO)
 * Purpose
 *   Runs MANUAL, LEVEL, LINE, OBSTACLE and MAPPING modes selected from
 *   the ESP32-CAM browser dashboard. Selection never starts motion; the
 *   operator must issue START and may always issue STOP.
 * Hardware
 *   Arduino UNO R3 with Sensor Shield v5.0; L298N; HC-SR04; SG90;
 *   four obstacle sensors; four cliff sensors; PCF8574T; LCD1602 I2C;
 *   MPU-6050; two 20-pulse wheel encoders; ESP32-CAM UART bridge.
 * Software
 *   Modular Arduino C/C++, non-blocking finite-state machines, fixed
 *   buffers, flash-resident status strings and a Timer2 UART at 9600.
 * Safety
 *   Mode change, STOP, browser loss and communication timeout stop the
 *   motors. Cliff recovery has final authority and may latch a lock.
 * Limitations
 *   LINE uses D2/D3 as line sensors and cannot simultaneously classify
 *   those signals as cliffs. MAPPING is dead-reckoning, not full SLAM.
 * Reference
 *   v4.0 Final, C. Vasileiou, MSc PADA, July 2026.
 **********/

#include <Arduino.h>
#include <Wire.h>
#include <Servo.h>
#include <LiquidCrystal_I2C.h>
#include <avr/interrupt.h>
#include <math.h>
#include <stdlib.h>
#include <string.h>

#include "Configuration.h"
#include "RobotTypes.h"
#include "TimerUart.h"
#include "Hardware.h"
#include "ModeManager.h"
#include "SafetyManager.h"
#include "ManualMode.h"
#include "LevelMode.h"
#include "LineMode.h"
#include "ObstacleMode.h"
#include "MappingMode.h"
#include "Protocol.h"

/******** function setup
 * Purpose
 *   Initializes the controller, peripherals and communication services.
 * Arguments
 *   None.
 * Results
 *   Updates state and/or hardware and returns no value.
 * Hardware
 *   Uses the shared Arduino UNO hardware layer as required.
 * Software
 *   Uses fixed state and bounded operations; no dynamic allocation.
 * Reference
 *   v4.0 Final, C. Vasileiou, July 2026.
 **********/
void setup(void) {
  Wire.begin();
  Wire.setWireTimeout(25000UL, true);

  lcd.init();
  lcd.backlight();
  reportStatus(F("TRITON-X v4"), F("Init hardware"));

  motors.begin();
  sonar.begin();
  pinMode(OBST_FL_PIN, INPUT);
  pinMode(CLIFF_LF_PIN, INPUT);
  pinMode(CLIFF_RF_PIN, INPUT);

  bool pcfOk = expander.begin(PCF8574_ADDR);
  pcfFaultLatched = !pcfOk;
  sensors.pcfHealthy = pcfOk;

  sonarServo.attach(SERVO_PIN);
  sonarServo.write(SERVO_CENTER);

  setupEncoderInterrupts();
  attachInterrupt(
    digitalPinToInterrupt(CLIFF_LF_PIN), cliffLeftFrontIsr, RISING
  );
  attachInterrupt(
    digitalPinToInterrupt(CLIFF_RF_PIN), cliffRightFrontIsr, RISING
  );

  reportStatus(F("TRITON-X v4"), F("Init MPU"));
  mpuHealthy = gyro.begin();
  if (mpuHealthy) {
    reportStatus(F("MPU CALIBRATE"), F("Keep robot still"));
    mpuHealthy = gyro.calibrate(400);
  }

  resetPoseAndEncoders();
  for (uint8_t sample = 0;
       sample < SENSOR_DEBOUNCE_SAMPLES;
       sample++) {
    refreshSensors(true);
    delay(5);
  }
  resetModeControllers(true);

  /* Start Timer2 only after all I2C initialization is complete. */
  espSerial.begin(9600);

  if (!sensors.pcfHealthy) {
    reportStatus(F("PCF8574 FAULT"), F("Check I2C"));
  } else if (!mpuHealthy) {
    reportStatus(F("READY / MPU ERR"), F("No mapping"));
  } else {
    reportStatus(F("TRITON-X READY"), F("Select mode"));
  }
}

/******** function loop
 * Purpose
 *   Runs the non-blocking supervisor and selected mode continuously.
 * Arguments
 *   None.
 * Results
 *   Updates state and/or hardware and returns no value.
 * Hardware
 *   Uses the shared Arduino UNO hardware layer as required.
 * Software
 *   Uses fixed state and bounded operations; no dynamic allocation.
 * Reference
 *   v4.0 Final, C. Vasileiou, July 2026.
 **********/
void loop(void) {
  processIncomingCommands();
  refreshSensors();
  processFrontCliffInterrupt();
  updateOdometry();
  handleLinkWatchdog();

  if (!sensors.pcfHealthy && modeRunning &&
      selectedMode != modeLine) {
    forceSystemStop(true);
    sendEvent(F("PCF_FAULT_STOP"));
    reportStatus(F("PCF8574 FAULT"), F("Motion stopped"));
  }

  handleCliffSafety();
  bool interruptHold = frontInterruptHoldBlocksMotion();
  if (safetyState == safetyIdle && !interruptHold) {
    runSelectedMode();
  }

  sendMappingPose();
  sendSystemTelemetry();
}

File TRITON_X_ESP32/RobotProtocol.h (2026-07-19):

/********** TRITON-X ESP32 supervisor and protocol bridge
 * Purpose
 *   Bridges browser commands to the Arduino UNO, parses telemetry and
 *   enforces a browser-disconnect STOP for every robot mode.
 * Hardware
 *   UART2: GPIO13 TX to Arduino D4; GPIO14 RX from level-shifted D13.
 * Software
 *   WebServer port 80, WebSocketsServer port 81 and fixed UART buffers.
 * Safety
 *   Only one browser is the active controller. Its disconnection sends
 *   STOP immediately and disables the optional camera stream.
 * Reference
 *   v4.0-rc5, C. Vasileiou, July 2026.
 **********/

#ifndef TRITON_X_ROBOT_PROTOCOL_H
#define TRITON_X_ROBOT_PROTOCOL_H

#include <Arduino.h>
#include <WiFi.h>
#include <WebServer.h>
#include <WebSocketsServer.h>
#include <math.h>
#include <stdlib.h>
#include <string.h>

WebServer httpServer(HTTP_PORT);
WebSocketsServer webSocket(WS_PORT);
HardwareSerial robotSerial(2);

int activeControllerClient = -1;
char serialBuffer[128];
uint8_t serialIndex = 0;
unsigned long lastHeartbeatMs = 0;
unsigned long lastMapBroadcastMs = 0;
unsigned long lastTelemetryBroadcastMs = 0;
unsigned long lastUnoLineMs = 0;
unsigned long lastControllerHeartbeatMs = 0;
bool controllerTimeoutLatched = false;

char robotMode[16] = "IDLE";
char robotSafety[16] = "SAFE";
char robotState[24] = "IDLE";
char lastEvent[48] = "Waiting for UNO";
bool robotRunning = false;
bool robotPcfHealthy = false;
bool robotMpuHealthy = false;
uint8_t robotCliffBits = 0;
uint8_t robotObstacleBits = 0;
float robotX = 0.0f;
float robotY = 0.0f;
float robotHeading = 0.0f;
float robotSonar = MAP_RAY_MAX_CM;
float robotTravel = 0.0f;
long robotEncoderLeft = 0;
long robotEncoderRight = 0;
unsigned long robotElapsedSeconds = 0;

/******** function sendRobotCommand
 * Purpose
 *   Sends one newline-delimited command to the Arduino UNO.
 * Arguments
 *   command Null-terminated UART or browser command.
 * Results
 *   Updates state and/or hardware and returns no value.
 * Hardware
 *   Uses ESP32-CAM communication or camera resources as required.
 * Software
 *   Uses bounded state and the ESP32 framework communication APIs.
 * Reference
 *   v4.0-rc5, C. Vasileiou, July 2026.
 **********/
void sendRobotCommand(const char* command) {
  robotSerial.println(command);
}

/******** function sendStop
 * Purpose
 *   Sends the global STOP command to the Arduino UNO.
 * Arguments
 *   None.
 * Results
 *   Updates state and/or hardware and returns no value.
 * Hardware
 *   Uses ESP32-CAM communication or camera resources as required.
 * Software
 *   Uses bounded state and the ESP32 framework communication APIs.
 * Reference
 *   v4.0-rc5, C. Vasileiou, July 2026.
 **********/
void sendStop(void) {
  sendRobotCommand("CMD:STOP");
}

/******** function unoOnline
 * Purpose
 *   Checks whether recent valid UART telemetry was received.
 * Arguments
 *   None.
 * Results
 *   Returns true when the reported condition or operation succeeds.
 * Hardware
 *   Uses ESP32-CAM communication or camera resources as required.
 * Software
 *   Uses bounded state and the ESP32 framework communication APIs.
 * Reference
 *   v4.0-rc5, C. Vasileiou, July 2026.
 **********/
bool unoOnline(void) {
  return lastUnoLineMs != 0 &&
    millis() - lastUnoLineMs <= UNO_OFFLINE_TIMEOUT_MS;
}

/******** function resetMapTelemetry
 * Purpose
 *   Clears the ESP32 map and associated pose telemetry.
 * Arguments
 *   None.
 * Results
 *   Updates state and/or hardware and returns no value.
 * Hardware
 *   Uses ESP32-CAM communication or camera resources as required.
 * Software
 *   Uses bounded state and the ESP32 framework communication APIs.
 * Reference
 *   v4.0-rc5, C. Vasileiou, July 2026.
 **********/
void resetMapTelemetry(void) {
  clearMap();
  robotX = 0.0f;
  robotY = 0.0f;
  robotHeading = 0.0f;
  robotTravel = 0.0f;
  robotElapsedSeconds = 0;
  robotEncoderLeft = 0;
  robotEncoderRight = 0;
}

/******** function parseSystemLine
 * Purpose
 *   Parses one Arduino system telemetry record.
 * Arguments
 *   payload Null-terminated command payload to parse.
 * Results
 *   Updates state and/or hardware and returns no value.
 * Hardware
 *   Uses ESP32-CAM communication or camera resources as required.
 * Software
 *   Uses bounded state and the ESP32 framework communication APIs.
 * Reference
 *   v4.0-rc5, C. Vasileiou, July 2026.
 **********/
void parseSystemLine(const char* payload) {
  char mode[16] = "IDLE";
  int running = 0;
  char safety[16] = "SAFE";
  char state[24] = "IDLE";
  unsigned int cliffBits = 0;
  unsigned int obstacleBits = 0;
  int pcf = 0;
  int mpu = 0;
  float sonar = MAP_RAY_MAX_CM;
  float heading = 0.0f;

  int parsed = sscanf(
    payload,
    "%15[^,],%d,%15[^,],%23[^,],%x,%x,%d,%d,%f,%f",
    mode,
    &running,
    safety,
    state,
    &cliffBits,
    &obstacleBits,
    &pcf,
    &mpu,
    &sonar,
    &heading
  );

  if (parsed == 10) {
    strncpy(robotMode, mode, sizeof(robotMode) - 1);
    robotMode[sizeof(robotMode) - 1] = '\0';
    strncpy(robotSafety, safety, sizeof(robotSafety) - 1);
    robotSafety[sizeof(robotSafety) - 1] = '\0';
    strncpy(robotState, state, sizeof(robotState) - 1);
    robotState[sizeof(robotState) - 1] = '\0';
    robotRunning = running != 0;
    robotCliffBits = (uint8_t)cliffBits;
    robotObstacleBits = (uint8_t)obstacleBits;
    robotPcfHealthy = pcf != 0;
    robotMpuHealthy = mpu != 0;
    robotSonar = sonar;
    robotHeading = heading;
  }
}

/******** function parsePoseLine
 * Purpose
 *   Parses one Arduino mapping pose telemetry record.
 * Arguments
 *   payload Null-terminated command payload to parse.
 * Results
 *   Updates state and/or hardware and returns no value.
 * Hardware
 *   Uses ESP32-CAM communication or camera resources as required.
 * Software
 *   Uses bounded state and the ESP32 framework communication APIs.
 * Reference
 *   v4.0-rc5, C. Vasileiou, July 2026.
 **********/
void parsePoseLine(const char* payload) {
  float x = 0.0f;
  float y = 0.0f;
  float heading = 0.0f;
  float sonar = 0.0f;
  char state[24] = "";
  long leftTicks = 0;
  long rightTicks = 0;
  float travel = 0.0f;
  unsigned long elapsed = 0;

  int parsed = sscanf(
    payload,
    "%f,%f,%f,%f,%23[^,],%ld,%ld,%f,%lu",
    &x,
    &y,
    &heading,
    &sonar,
    state,
    &leftTicks,
    &rightTicks,
    &travel,
    &elapsed
  );

  if (parsed == 9) {
    robotX = x;
    robotY = y;
    robotHeading = heading;
    robotSonar = sonar;
    robotEncoderLeft = leftTicks;
    robotEncoderRight = rightTicks;
    robotTravel = travel;
    robotElapsedSeconds = elapsed;
    strncpy(robotState, state, sizeof(robotState) - 1);
    robotState[sizeof(robotState) - 1] = '\0';
    markPath(robotX, robotY);
  }
}
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

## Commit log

2026-07-18 Rename MPU6050 Module.SLDPRT to TRITON X CAD/MPU6050 Module.SLDPRT
    [MPU6050 Module.SLDPRT]
2026-07-18 Rename Motor Casing.sldprt to TRITON X CAD/Motor Casing.sldprt
    [Motor Casing.sldprt]
2026-07-18 Rename PCF8574_RED Multiplexer v12.SLDPRT to TRITON X CAD/PCF8574_RED Multiplexer v12.SLDPRT
    [PCF8574_RED Multiplexer v12.SLDPRT]

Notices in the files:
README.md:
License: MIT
